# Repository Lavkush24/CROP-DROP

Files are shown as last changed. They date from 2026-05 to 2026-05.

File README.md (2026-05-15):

# 🌾 Crop Drop Bot — eYantra Robotics Competition 2025
### Team CB#3084 | Tasks 1 → 5

A fully autonomous line-following robot that detects coloured crop boxes,
navigates a grid arena via PID and Q-Learning, and physically picks up and
drops boxes at the correct destination zones.

---

## Table of Contents
- [Project Overview](#project-overview)
- [Robot Photos](#robot-photos)
- [Repository Structure](#repository-structure)
- [Task 1 — Environment Setup & Algorithm Design](#task-1)
- [Task 2 — Simulation: Color Detection, Navigation & Drop Logic](#task-2)
- [Task 3 — Hardware Assembly](#task-3)
- [Task 4 — Real Arena: Black Line Following](#task-4)
- [Task 5 — Dual Line Following (Black + White)](#task-5)
- [Key Technical Challenges & How I Solved Them](#challenges)
- [Hardware Stack](#hardware-stack)
- [Software Stack](#software-stack)
- [PID Tuning Reference](#pid-tuning)
- [How to Run](#how-to-run)
- [Demo Videos](#demo-videos)
- [Results](#results)

---

## Project Overview

The **Crop Drop Bot** is an autonomous robot designed for the eYantra 2025 competition.
It follows both black and white lines on a printed arena, reads the colour of cargo boxes
using an onboard colour sensor, communicates with a backend server, and deposits each
box at the matching colour-coded destination zone — all without human intervention.

The project progressed through five tasks, moving from pure simulation in CoppeliaSim
to a fully assembled physical robot running on a real printed arena. Tasks 1–4 were
completed successfully. The team was eliminated at Task 5 due to a hardware constraint:
no single IR sensor mounting height could produce readings that distinguished both
black and white lines reliably at the same time on the physical arena.

---

## Robot Photos

| Top view | Front view | Side view |
|:---:|:---:|:---:|
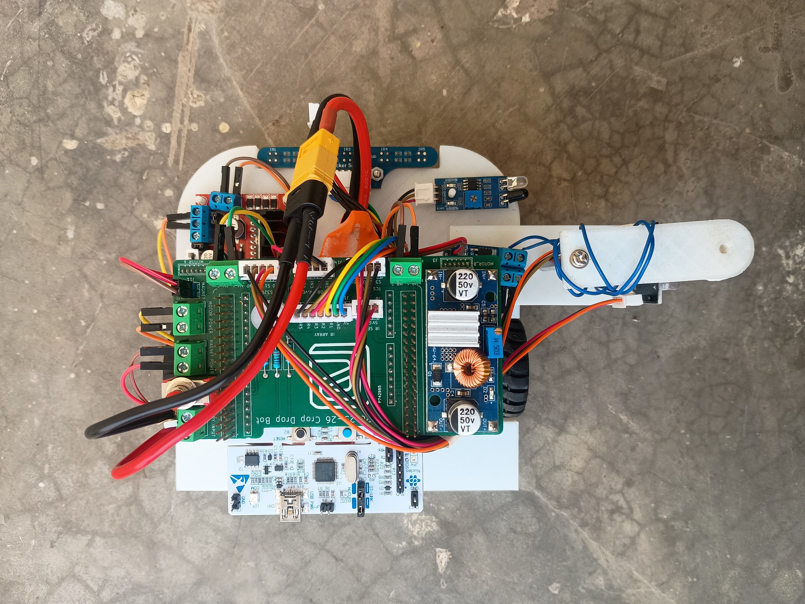
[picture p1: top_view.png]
Top view
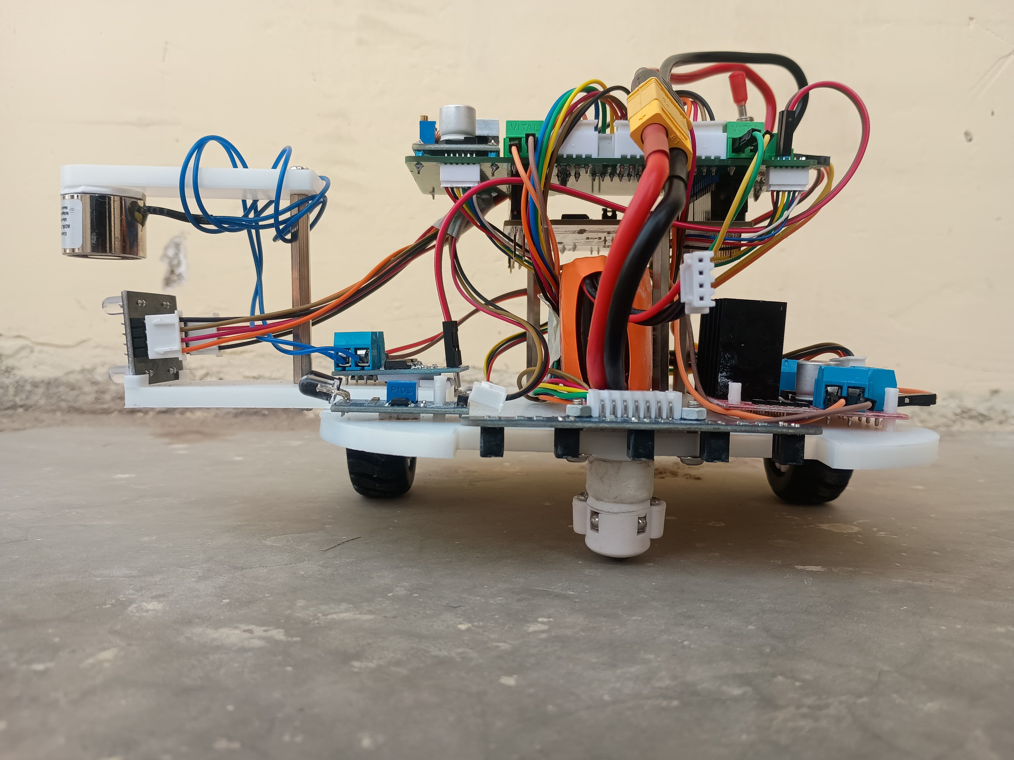
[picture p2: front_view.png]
Front view
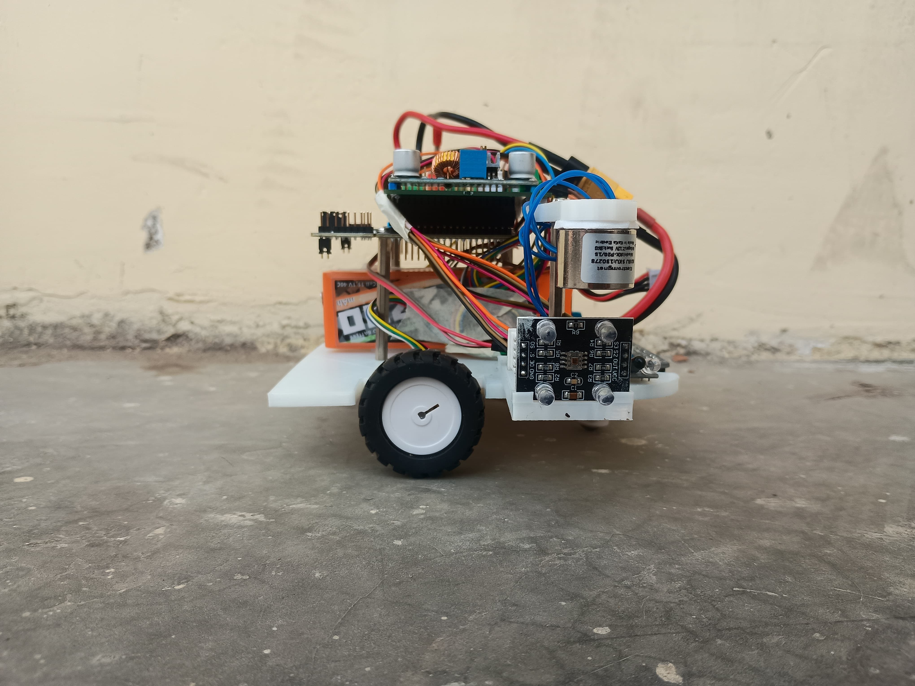
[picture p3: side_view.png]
Side view
|  |  |  |

---

## Repository Structure

```
crop_drop/
├── CB_3084_Task_1B_rl/          # Task 1B/1C — Q-Learning implementation
│   ├── Qlearning.py             #   Core Q-table training loop
│   ├── Train.py                 #   Training entry point
│   ├── Test.py                  #   Policy evaluation
│   ├── Connector.py             #   CoppeliaSim socket bridge
│   ├── wrapper/                 #   Environment wrapper
│   ├── q_table.pkl              #   Trained Q-table (binary)
│   └── result.json              #   Training metrics
│
├── crop_drop_task_2/            # Task 2 — Simulation navigation
│   ├── crop.txt                 #   Dev notes & sensor logs
│   ├── ubuntu 24-20251107T131635Z-1-001/   # PID implementation (Task 2A)
│   └── ubuntu 24-20251111T121329Z-1-001/   # RL algorithm using Q-Learning (Task 2B)
│
├── crop_drop_task_3/            # Task 3 — PCB & mechanical
│   ├── CB#3084_3A.zip           #   Onshape / 3D model files
│   ├── CB_PCB_schematics.pdf    #   PCB schematic
│   ├── CB_Gerber/               #   Gerber files for fabrication
│   ├── STEP files/              #   3D printable parts
│   ├── stm ioc files/           #   STM32 IOC config
│   └── Task3_arena_testing.ttt  #   CoppeliaSim scene
│
├── crop_drop_task_4/            # Task 4 — Black line, real arena
│   ├── Task4a_PID/              #   PID controller source
│   ├── Task4b_RL/               #   RL policy deployment
│   └── Verify_task4a/           #   Verification scripts
│
├── crop_drop_task_5/            # Task 5 — Dual line mode
│   └── Task5a_PID/              #   Combined black+white PID
│
├── top_view.png                 # Arena top-view reference photo
├── front_view.png               # Robot front view
├── side_view.png                # Robot side view
├── crop drop.txt                # CoppeliaSim sensor log (Task 2 development notes)
├── Crop Drop Testing.txt        # Real hardware build & PID tuning log (Task 3/4)
└── .gitignore
```

---

## Task 1 — Environment Setup & Algorithm Design 

### Task 1A — Ubuntu Setup
The competition required Ubuntu 24 as the working environment.

**What I did:**
- Installed Ubuntu 24 alongside Windows (dual-boot)
- Set up CoppeliaSim, Python 3, and all required simulation libraries
- Configured the socket communication bridge between Python and CoppeliaSim (`Connector.py`)

### Task 1B — PID Line Following
Implemented a classic 5-sensor weighted PID controller.

**Error calculation (weighted position):**
```
Sensor weights: [-2, -1, 0, 1, 2]
error = Σ(weight[i] × sensor[i]) / Σ(sensor[i])
```

**Tuned parameters (simulation):**
```
Kp = 1.45,  Ki = 0.03,  Kd = 0.01
base_speed = 4.0
```

### Task 1C — Reinforcement Learning (Q-Learning)
Implemented a tabular Q-Learning agent as an alternative to PID.

**Key design decisions:**
- State: discretised sensor reading pattern
- Actions: `[hard_left, left, straight, right, hard_right]`
- Reward: +10 on-line, −5 off-line, −1 per step
- Trained policy serialised to `q_table.pkl` and loaded at inference time

---

## Task 2 — Simulation: Color Detection, Navigation & Drop Logic 

This was the most algorithmically complex task, involving colour detection,
junction navigation, and precise drop placement — all inside CoppeliaSim.

### 2A — Color Detection

**Problem:** CoppeliaSim's rendering pipeline returns non-standard raw RGB values
that don't map intuitively to actual colours.

**Raw values observed (before normalisation):**

| Color | Raw R | Raw G | Raw B |
|---|---|---|---|
| Blue  | 0.098 | 0.000 | 0.000 |
| Red | 0.188 | 0.569 | 0.000 |
| Green | 0.188 | 0.000 | 0.569 |

**Fix — dominance mapping:** Rather than comparing absolute values,
I normalised the three channels and classified by whichever channel was dominant.
This made detection robust to the non-linear rendering pipeline.

### 2A — Junction Detection

The 5-sensor array gives distinct signatures at junctions vs. straight lines.

**Straight line:**
```
[0.83, 0.83, 0.03, 0.83, 0.83]   → outer 4 high, centre low
```

**Junction (T or cross):**
```
[0.83, 0.83, 0.03, 0.83, 0.83]   → multiple high readings fade
[0.83, 0.44, 0.03, 0.46, 0.83]   → then inner sensors drop
[0.62, 0.03, 0.03, 0.32, 0.63]   → transition zone
[0.37, 0.03, 0.03, 0.05, 0.03]   → robot centred on junction
```

**Condition to detect junction:**
```C
if(isBlack(c) && !junction && boxPicked) {
    printf("Node is detected\n");
    SLEEP(10);
    set_motor(c,0,0);
    
    printf("color of Box: %c\n",colorDetected);
    char dir = chooseDirection(colorDetected);
    printf("Turn Direction: %c \n",dir);
}
```

### 2A — Destination Zone Detection

Instead of using the colour sensor on the floor (unreliable at low angle),
I used the box color to detect the direction as its mapped for each color there sperate direction in which i need to move.

```C
char chooseDirection(char boxColor) {
    char dir;
    if(boxColor == 'R') {
        dir = 'L';
    }
    else if(boxColor == 'G') {
        dir = 'R';   
    }
    else if(boxColor == 'B') {
        dir = 'F';
    }
    return dir;   
}
```

### 2B — Dual Line Following + Full Path

**White line (inverted logic):**
White line = high reading on centre sensor, low on outer sensors.
```
[0.09, 0.09, 0.83, 0.09, 0.09]   ← centre sensor high = ON white line
```
Error computed by inverting weights so PID steers toward the high centre value.

**Black line (normal logic):**
Black line = low reading on the sensor directly above it, high on surroundings.
```
[0.83, 0.03, 0.83, 0.83, 0.83]   ← sensor 2 low = ON black line
```

**Line-type classifier:**
```cpp
bool isBlack(SocketClient* c) {
    float ir1 = c->line_sensors[0];  // left_corner sensor
    float ir2 = c->line_sensors[1];  // left sensor
    float ir3 = c->line_sensors[2];  // middle sensor (center)
    float ir4 = c->line_sensors[3];  // right sensor
    float ir5 = c->line_sensors[4];

    if(ir1 < 0.4 && ir2 < 0.4 && ir3 < 0.4 && ir4 < 0.4 && ir5 < 0.4) {
        return true;
    }
    return false;
}
```

**Corner conflict fix — `corner_duration` counter:**

At corners, the sensor array reads a mix of black+high values that momentarily
satisfy both black and white conditions. Adding a persistence counter (`corner_duration = 25`)
means the robot only switches line-type classification after 25 consecutive
matching frames, preventing thrashing.

```cpp
corner_duration = 25;  // frames the corner pattern must persist before acting
```

**PID re-tuning after box pickup:**

With the box loaded, the robot's centre of mass shifts and the effective turning
radius changes. Corners failed without a separate loaded-state PID set:

```
Unloaded:  Kp = 1.45, Ki = 0.03, Kd = 0.01
Loaded:    Kp = 1.10, Ki = 0.02, Kd = 0.05   (more damping, less aggression)
```

---

## Task 3 — Hardware Assembly 

### Mechanical
The chassis was split into three separate 3D-printed parts to make assembly and
sensor positioning adjustable:
- **Base** — motor mounts, wheel wells, main body
- **Colour sensor mount** — angled bracket to hold the sensor at correct reading height
- **Magnet holder** — gripper mechanism for picking up boxes

STEP files are in `crop_drop_task_3/STEP files/`.

### Electronics
- Microcontroller: STM32 Nucleo (configured via `.ioc` files)
- Motor drivers wired to the STM32 PWM outputs
- 5× IR reflectance sensors on underside bracket
- Colour sensor positioned to read boxes at pick-up height
- PCB designed in KiCad — Gerber files in `CB_Gerber/`

### Wiring reference
See `CB_PCB_schematics.pdf` for full schematic.

### How to read IR sensor output (hardware debug)
```bash
# Connect the Nucleo board via USB, then:
ls /dev/ttyACM*                              # find the port
putty -fn "Monospace 12"                     # launch PuTTY with readable font
# In PuTTY: Connection Type = Serial, Speed = 115200, Serial line = /dev/ttyACM0
```

### Bring-up: IR sensor ADC → reflectance conversion

Raw ADC values: maximum on white, minimum on black.
First step was converting to reflectance percentage (0 = black, 100 = white).

**Problem encountered:** the conversion was not producing middle values —
readings jumped directly between 0 and 100 with nothing in between.
This was traced to missing normalisation in the ADC-to-percentage mapping
and was fixed before PID tuning began.

### Real hardware PID tuning — the actual journey

The position error uses weighted sensors `{-2, -1, 0, 1, 2}` multiplied by 10
to give enough steering authority (raw weights alone were too small).

**Stage 1 — find critical Kp (Ki = Kd = 0):**

| Kp | Observed behaviour |
|---|---|
| 15 | Slight oscillation — borderline usable |
| 15–16 | ⭐ Critical point — oscillates but follows |
| 18 | Follows straight, won't turn at corners |
| 32 | Still won't turn |
| 46 | Very small turn — not usable |

Initial tuning stalled here because the position weights `{-2,-1,0,1,2}` were
too small. Multiplying by 10 gave enough correction range to actually steer.

**Stage 2 — add Kd to kill oscillation:**
```
Kd ≈ Kp × 0.2  →  Kd = 15 × 0.2 = 3
```

**Stage 3 — alignment issue:**
The bot followed straight paths but was physically offset — centred over sensor 4
instead of sensor 3. Two options considered:
- Individual sensor calibration *(correct long-term fix)*
- Setpoint offset `setPoint = -2.0f` *(used as temporary workaround)*

**Stage 4 — corner turning problem:**

At `base_speed = 80` the PID correction alone couldn't steer the robot through
corners. A `turn_boost` and `speed_scale` were added but caused jerky motion and
occasional line-loss.

The real fix was **dynamic speed** — reduce wheel speed proportionally to error
magnitude so the robot naturally slows at corners:

```c
dynamic_speed = base_speed - (k_speed * abs(error));
// At corners: error ≈ 1.5–2.0
// k_speed = 3  →  speed reduced by 4.5–6.0 at corners
```

**Stage 5 — dt term was missing from PID:**

The integral and derivative terms were not being scaled by `dt` (time between
updates). After adding it:
- At `Kp = 1, Ki = Kd = 0, base_speed = 120`: robot drifts
- At `Ki = 16`: robot starts turning — confirmed dt fix was working
- Behaviour from Ki = 16 to Ki = 50 was consistent (only zigzag amplitude changed)
  because at speed 120 the maximum PID correction was already at its steering limit

**Stage 6 — smooth speed ramp-up:**

Setting `turn_boost` and `speed_scale` as global variables caused the motors to
snap to the reduced corner speed on the very first corner and never recover.
A gradual speed ramp mechanism was needed — increase speed continuously rather
than jumping — similar to how a real vehicle accelerates.

**Final working parameters (Task 3 verification):**
```
Kp = 19,  Ki = 1,  Kd = 2
base_speed = 80,  min_speed = 10
speed_scale = 0.8,  turn_boost = 1.5,  k_speed = 3
Path accuracy: ~80%
```

---

## Task 4 — Real Arena: Black Line Following 

First full run on the **physically printed** competition arena, carrying forward
the hardware PID foundation from Task 3.

**Key differences encountered vs Task 3 bench testing:**
- Real arena ink has softer edges than the test track — junction thresholds loosened
- Reflective paper surface adds noise — moving-average smoothing added to sensor reads
- Motors don't respond linearly at low PWM — deadband compensation added

**PID re-tuned for full arena speed:**
```
Kp = 1.80,  Ki = 0.02,  Kd = 0.08
base_speed = 3.5  (reduced from 80 PWM units — arena safety margin)
```

Both PID (Task 4A) and RL policy from Task 1C (Task 4B) were deployed and compared.
PID outperformed RL on the physical arena because the Q-table was trained on
clean simulation sensor readings that don't match the noise profile of real hardware.

---

## Task 5 — Dual Line Following (Black + White) ⚠️ Elimination Point 

The Task 5 arena mixes both black and white line segments on the same track.
The robot must autonomously detect which type it is currently on and flip PID
error polarity accordingly.

**The software approach worked in simulation:**
```python
def detect_line_type(sensors):
    centre = sensors[2]
    outer_avg = (sensors[0] + sensors[4]) / 2
    if centre > 0.7 and outer_avg < 0.2:
        return "white"       # bright centre, dark edges
    elif centre < 0.2 and outer_avg > 0.7:
        return "black"       # dark centre, bright edges
    else:
        return "unknown"     # transition — hold last known type
```

### ❌ Why we were eliminated

**Root cause: IR sensor mounting height.**

In simulation both line types produced clean, separable readings because the
virtual sensors have no physical constraints. On the real robot, the 5 IR
sensors are fixed at one physical height above the floor.

The problem is that the threshold values that make white-line detection work
conflict with the threshold values needed for black-line detection at the same
mounting height:

| Sensor height | White line centre reading | Black line low reading | Conflict? |
|---|---|---|---|
| Too low | ~0.83 (saturated, clear) | ~0.03 (clear) | ✅ No conflict — but robot physically scrapes floor at turns |
| Optimal for black | ~0.55 (detectable) | ~0.03 (clear) | ⚠️ White-line readings drop into ambiguous range |
| Optimal for white | ~0.83 (clear) | ~0.35 (too high) | ⚠️ Black line no longer reads low enough to distinguish |

Every height we tried either made white-line detection unreliable or pushed the
black-line low reading up into the range where the classifier got confused during
transitions. The `corner_duration` filter that worked in Task 2 simulation was not
enough to mask the ambiguity on the physical track.

**What we tried:**
- Adjusting sensor array height in 1 mm increments (3 mm → 8 mm from floor)
- Recalibrating thresholds for each height separately
- Using a longer `corner_duration` window to filter transition noise
- Running at lower speed to give the sensor more time to settle

None of these resolved the fundamental overlap in reading ranges between the two
line types at a single fixed height.

**What would have fixed it:**
- An adjustable sensor arm that could tilt the array slightly (changes the
  effective angle, not just height) — small tilt changes white vs black contrast
  independently
- Using two separate sensor arrays at different heights, one tuned for each line
- A sensor with higher dynamic range so the two reading bands don't overlap

---

## Key Technical Challenges & How I Solved Them 

| Challenge | Root Cause | Solution |
|---|---|---|
| Wrong colour detection in sim | CoppeliaSim non-standard rendering pipeline | Channel-dominance normalisation instead of absolute RGB thresholds |
| IR sensor ADC not returning middle values | Missing normalisation in ADC-to-reflectance conversion | Fixed mapping so values span full 0–100 range |
| PID couldn't steer at corners (Kp up to 46) | Position weights `{-2,-1,0,1,2}` too small for enough correction range | Multiplied weights by 10 to give sufficient steering authority |
| Robot physically offset — followed line on sensor 4 not sensor 3 | Mechanical misalignment of sensor bracket | Temporary: `setPoint = -2.0f` offset. Proper fix: per-sensor calibration |
| Jerky motion at corners with `turn_boost` | Global speed variables snapped to corner values and never recovered | Replaced with `dynamic_speed = base_speed − (k_speed × |error|)` so speed reduces smoothly with error magnitude |
| Missing `dt` in PID made integral/derivative wrong | PID update loop ran at variable rate with no time scaling | Added `dt` term; re-tuned from scratch after fix |
| Junction over-detection | Transition frames look like junctions | Added consecutive-frame counter before triggering junction logic |
| Corner thrashing (black vs white) | Mixed sensor readings at corners | `corner_duration = 25` persistence filter |
| Robot can't turn after box pickup | Shifted CoM changes dynamics | Separate loaded/unloaded PID parameter sets |
| Floor colour undetectable by colour sensor | Sensor angle too shallow for flat surface | Switched to flat-value detection using line sensor array average |
| RL underperforms on real arena | Sim sensor noise doesn't match real hardware | Kept RL as fallback; deployed PID for competition runs |
| Black line junction readings change after pickup | Box blocks one sensor slightly | Re-calibrated junction threshold: all sensors `< 0.30` instead of `< 0.10` |
| ❌ **No single sensor height works for both line types** (Task 5 — **unsolved**) | Fixed sensor array height creates overlapping reading ranges for black and white lines on the physical robot | Tried height adjustments (3–8 mm), threshold recalibration, longer persistence window, lower speed — none fully resolved the overlap. Would need an angled/adjustable sensor arm or a dual-array setup |

---

## Hardware Stack 

| Component | Part |
|---|---|
| Microcontroller | STM32 |
| Motors | DC gear motors × 2 |
| Line sensors | IR reflectance array × 5 |
| Colour sensor | TCS3200 (or equivalent) |
| Gripper | Servo-actuated custom 3D-printed |
| Power | LiPo battery + regulator |
| Chassis | Custom 3D-printed (STEP files included) |

---

## Software Stack 

| Layer | Technology |
|---|---|
| Simulation | CoppeliaSim EDU |
| Robot–sim bridge | Python socket (`Connector.py`) |
| Control algorithm | PID + Q-Learning (Python) |
| Firmware | STM32 HAL (C) |
| Training | Custom Q-Learning (`Qlearning.py`) |
| Build system | Make / STM32CubeIDE |

---

## PID Tuning Reference 

```
Context                 Kp      Ki      Kd      base_speed
─────────────────────────────────────────────────────────
Sim — white line        1.45    0.03    0.01    4.0
Sim — black line        1.45    0.03    0.01    4.0
Sim — loaded (black)    1.10    0.02    0.05    3.5
Real arena (Task 4)     1.80    0.02    0.08    3.5
Real arena — loaded     1.30    0.02    0.10    3.0
```

---

## How to Run 

### Simulation (Tasks 1–2)

```bash
# 1. Open the scene in CoppeliaSim
#    File → Open → Task3_arena_testing_modified.ttt

# 2. Install Python dependencies
pip install -r requirements.txt

# 3. Train Q-Learning (Task 1C)
cd CB_3084_Task_1B_rl
python Train.py

# 4. Run PID controller
python Test.py --mode pid

# 5. Run RL controller
python Test.py --mode rl
```

### Real Hardware (Tasks 4–5)
float compute_line_conf(float *r)
{
    float s = 0.0f;
    for (int i = 0; i < NUM_SENSORS; i++) s += r[i];
    return s;
}
```bash
# Flash firmware via STM32CubeIDE
# Open project in crop_drop_task_4/Task4a_PID
# Build → Flash to board
# Place robot on arena start position → power on
```

---

## Demo Videos

> Click a thumbnail to open and play the video .

### Task 4 — Black line following on real arena

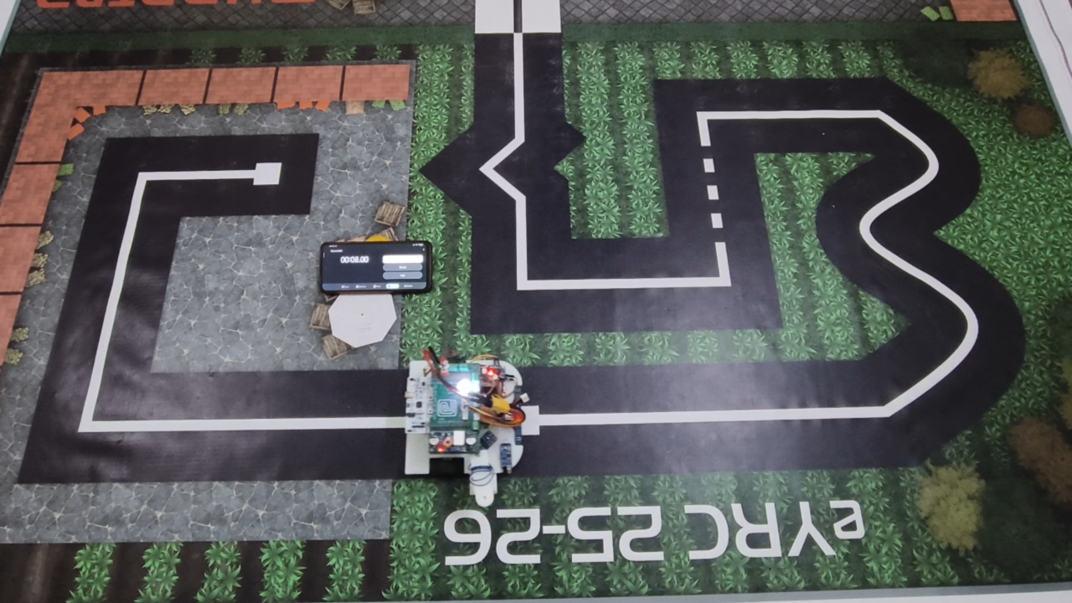
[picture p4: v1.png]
Task 4 run — black line (https://youtu.be/oO3rsXFNNNE)


### Task 4 —  Box pickup run

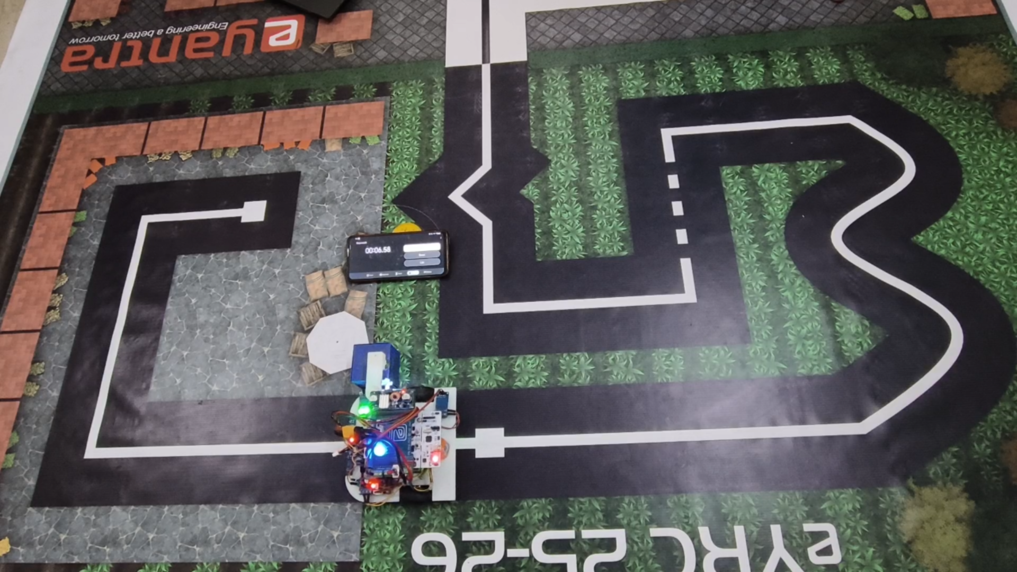
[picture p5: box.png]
Task 4 run — alternate angle (https://youtu.be/H0FVPsiAQus)


---

## Results

| Task | Status | Notes |
|---|---|---|
| 1A — Ubuntu setup | ✅ Complete | Dual-boot, CoppeliaSim configured |
| 1B — PID sim | ✅ Complete | Stable line following achieved |
| 1C — Q-Learning | ✅ Complete | Policy converges after ~500 episodes |
| 2A — Colour + nav | ✅ Complete | Junction stop + colour-directed routing |
| 2B — Dual line + pick/drop | ✅ Complete | Both line types, corner fix applied |
| 3 — Hardware assembly | ✅ Complete | Robot assembled and functional |
| 4 — Real arena black line | ✅ Complete | PID outperforms RL on real hardware |
| 5 — Dual line real arena | ❌ Eliminated | IR sensor reading ranges for black and white lines overlap at every tested mounting height; no single fixed position produced clean discrimination on the physical robot |

---

> **Competition:** eYantra Robotics Competition 2025
> **Team ID:** CB#3084
> **Theme:** Crop Drop Bot

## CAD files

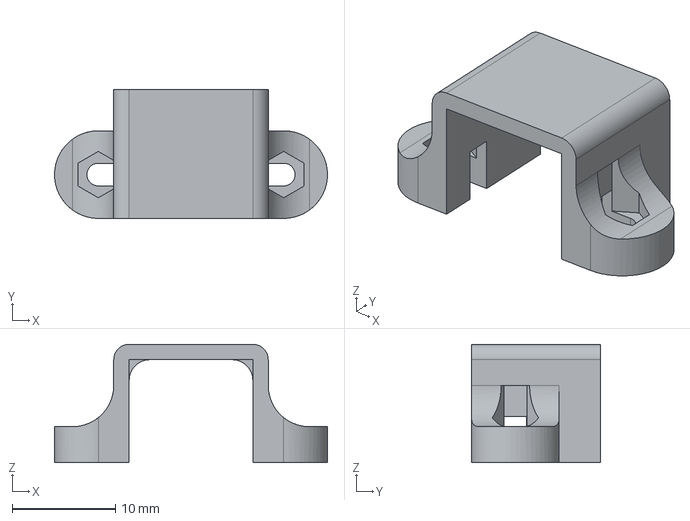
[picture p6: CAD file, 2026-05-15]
crop_drop_task_3/STEP files/motor mount-Body.step
26.5 x 12.5 x 11.5 mm

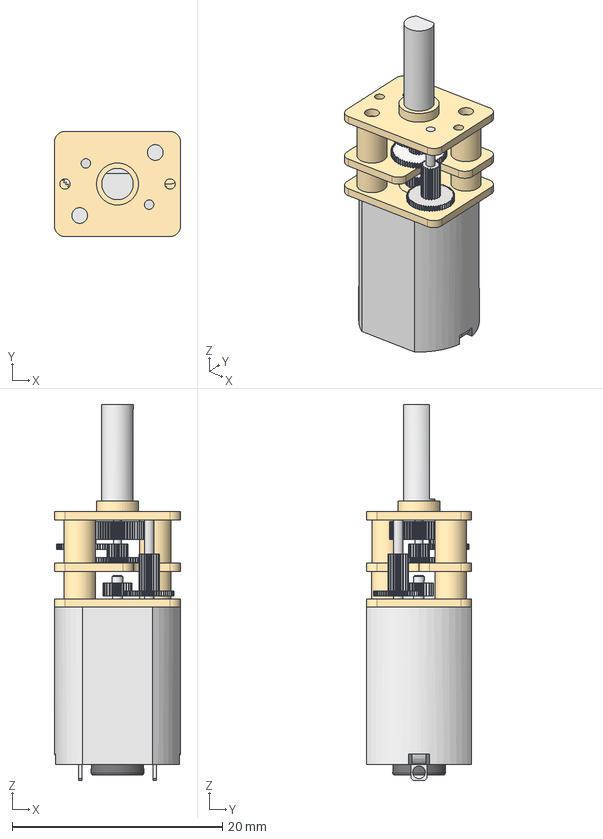
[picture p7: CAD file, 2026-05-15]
crop_drop_task_3/STEP files/n20-dc-gear-motor-1.snapshot.1/N20 DC Gear Motor/N20 DC Gear Motor.step
12.0 x 10.0 x 35.8 mm
Gear Box
Shaft
Motor

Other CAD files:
crop_drop_task_3/STEP files/n20-dc-gear-motor-1.snapshot.1/N20 DC Gear Motor/N20 DC Gear Motor.f3d

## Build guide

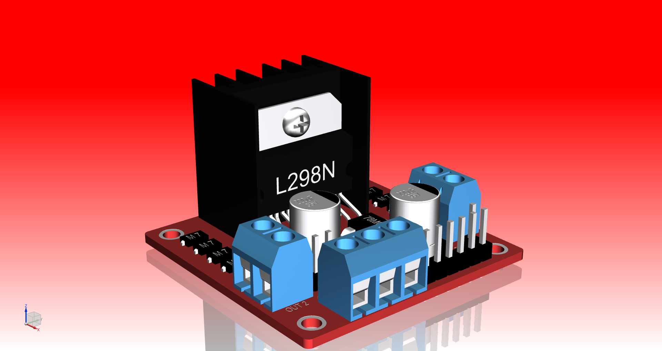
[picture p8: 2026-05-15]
crop_drop_task_3/STEP files/l295n-motor-driver-module-1.snapshot.2/L298NNN.png

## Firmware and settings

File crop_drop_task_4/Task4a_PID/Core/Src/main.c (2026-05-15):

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
/* Includes ------------------------------------------------------------------*/
#include "main.h"

/* USER CODE BEGIN Includes */
#include "stdio.h"
#include "stdlib.h"
#include "math.h"
#include "stdbool.h"
#include "stdint.h"

/* USER CODE END Includes */

/* USER CODE BEGIN PD */
#define NUM_SENSORS        5
#define BASE_SPEED         60
#define TURN_SPEED         BASE_SPEED * 2.2
#define GAP_SPEED          60
#define MAX_PWM            150
#define MIN_ACTIVE_PWM     10
#define LEFT_TRIM   	   0.92f
#define RIGHT_TRIM 		   1.00f

#define MAX_CORRECTION     30.0f
#define CORNER_TH          0.7f
#define TURN_TIME_MS       140

#define LINE_LOST_ENTER    0.45f
#define LINE_LOST_EXIT     0.65f
#define PIVOT_POS_TH       0.65f


// color detect
#define LED_R_PORT GPIOC
#define LED_R_PIN  GPIO_PIN_6

#define LED_G_PORT GPIOC
#define LED_G_PIN  GPIO_PIN_8

#define LED_B_PORT GPIOC
#define LED_B_PIN  GPIO_PIN_9

// obstacle detection
#define IR_OUT_PORT GPIOA
#define IR_OUT_PIN  GPIO_PIN_15

// magnet
#define EM_PORT GPIOA
#define EM_PIN  GPIO_PIN_4

/* USER CODE END PD */

ADC_HandleTypeDef hadc1;
DMA_HandleTypeDef hdma_adc1;

TIM_HandleTypeDef htim2;
TIM_HandleTypeDef htim3;

UART_HandleTypeDef huart2;

/* USER CODE BEGIN PV */

/* helper function required */

typedef struct {
	float kp;
	float ki;
	float kd;
	float prev_error;
	float integral;
} PID_t;

typedef enum {
    MODE_TRACK,
    MODE_PIVOT,
    MODE_GAP,
	PICK_BOX,
	NODE_MODE
} ControlMode;

//static int slow_hold = 0;
volatile uint16_t adcBuffer[5];
char buffer[64];

float black[5];
float white[5];


// color detection
volatile uint32_t capture1 = 0, capture2 = 0;
volatile uint8_t  captureDone = 0;
volatile uint32_t frequency = 0;

typedef enum {
    COLOR_UNKNOWN,
    COLOR_RED,
    COLOR_GREEN,
    COLOR_BLUE
} DetectedColor;

static uint32_t led_last_tick = 0;
static uint8_t  led_on = 0;
static DetectedColor led_color = COLOR_UNKNOWN;

//static float prev_pos = 0.0f;
float speed_scale = 1.0f;
static float last_pos = 0.0f;
static bool in_gap = false;
static bool box_picked = false;

/* USER CODE END PV */

void SystemClock_Config(void);
static void MX_GPIO_Init(void);
static void MX_DMA_Init(void);
static void MX_USART2_UART_Init(void);
static void MX_ADC1_Init(void);
static void MX_TIM2_Init(void);
static void MX_TIM3_Init(void);


/* USER CODE BEGIN PFP */

// hardware control functions
void custom_control(int left,int right);

// helper functions
int clamp(int val,int min,int max);
float clampFloat(float v, float min, float max);
void pidInit(PID_t *pid,float kp,float ki,float kd);
void ir_state(const uint16_t *adc, uint8_t *state);
void readIR(uint16_t *dst);
void computeReflectance(uint16_t* adcBuffer, float *ir_reflectance);
float position_reflectance(const float *ir);
float position_states(uint8_t *state);
float pid_compute(PID_t *pid, float error, float dt);
void set_threshold(uint16_t* adcBuffer);
void calibrate_sensor(uint32_t duration_ms);



float compute_line_conf(float *r);
void control_track(float steer, float speed,float left_scale, float right_scale,int *left, int *right);
void control_pivot(float pos, int *left, int *right);
void control_gap(float last_pos, int *left, int *right);

// colord erection
DetectedColor TCS3200_DetectColor(void);
void LED_BlinkColor(DetectedColor color, uint32_t period_ms);
uint32_t Read_Color_Frequency(uint8_t s2, uint8_t s3);
uint8_t IR_ObjectDetected(void);

/* USER CODE END PFP */

/* USER CODE BEGIN 0 */
static inline void Electromagnet_ON(void)
{
    HAL_GPIO_WritePin(EM_PORT, EM_PIN, GPIO_PIN_SET);
}

static inline void Electromagnet_OFF(void)
{
    HAL_GPIO_WritePin(EM_PORT, EM_PIN, GPIO_PIN_RESET);
}

static inline void LED_AllOff(void)
{
    HAL_GPIO_WritePin(LED_R_PORT, LED_R_PIN, GPIO_PIN_SET);
    HAL_GPIO_WritePin(LED_G_PORT, LED_G_PIN, GPIO_PIN_SET);
    HAL_GPIO_WritePin(LED_B_PORT, LED_B_PIN, GPIO_PIN_SET);
}

static inline void LED_SetColor(DetectedColor color)
{
    LED_AllOff();  // important

    switch (color)
    {
    case COLOR_RED:
        HAL_GPIO_WritePin(LED_R_PORT, LED_R_PIN, GPIO_PIN_RESET);
        break;

    case COLOR_GREEN:
        HAL_GPIO_WritePin(LED_G_PORT, LED_G_PIN, GPIO_PIN_RESET);
        break;

    case COLOR_BLUE:
        HAL_GPIO_WritePin(LED_B_PORT, LED_B_PIN, GPIO_PIN_RESET);
        break;

    default:
        // unknown → all off
        break;
    }
}



/* USER CODE END 0 */

/**
  * @brief  The application entry point.
  * @retval int
  */
int main(void)
{

  /* MCU Configuration--------------------------------------------------------*/

  /* Reset of all peripherals, Initializes the Flash interface and the Systick. */
  HAL_Init();

  /* Configure the system clock */
  SystemClock_Config();

  /* Initialize all configured peripherals */
  MX_GPIO_Init();
  MX_DMA_Init();
  MX_USART2_UART_Init();
  MX_ADC1_Init();
  MX_TIM2_Init();
  MX_TIM3_Init();

  /* USER CODE BEGIN 2 */
  HAL_ADC_Start_DMA(&hadc1,(uint32_t*)adcBuffer,5);
  HAL_Delay(200);

  calibrate_sensor(5000);

  // motor control pin configuration
  HAL_TIM_PWM_Start(&htim2, TIM_CHANNEL_1);
  HAL_TIM_PWM_Start(&htim2, TIM_CHANNEL_2);
  HAL_TIM_PWM_Start(&htim2, TIM_CHANNEL_3);
  HAL_TIM_PWM_Start(&htim2, TIM_CHANNEL_4);


  // color freq
  HAL_GPIO_WritePin(GPIOB, GPIO_PIN_12, GPIO_PIN_SET);
  HAL_GPIO_WritePin(GPIOB, GPIO_PIN_13, GPIO_PIN_SET);
  HAL_TIM_IC_Start_IT(&htim3, TIM_CHANNEL_1);

  PID_t linePID;
  pidInit(&linePID, 15.0f, 0.0f, 0.0f);

  uint32_t lastTick = HAL_GetTick();

  /* USER CODE END 2 */

  /* Infinite loop */
  /* USER CODE BEGIN WHILE */
  while (1)
  {
	  // -------------------- Time --------------------
	  uint32_t now = HAL_GetTick();
	  float dt = (now - lastTick) / 1000.0f;
	  lastTick = now;

	  if (dt <= 0.0f || dt > 0.1f)
	      dt = 0.01f;

	  // -------------------- Sensors --------------------
	  uint16_t ir[NUM_SENSORS];
	  float reflectance[NUM_SENSORS];
	  readIR(ir);
	  computeReflectance(ir, reflectance);
	  // -------------------- Position --------------------
	  float pos = position_reflectance(reflectance);   // pos < 0 : left, pos > 0 : right

	  // color detection
	  DetectedColor color = TCS3200_DetectColor();
	  bool box = IR_ObjectDetected();

	  if(color != COLOR_UNKNOWN && !box_picked) {
		  LED_SetColor(color);
	  }
	  else {
		  LED_SetColor(COLOR_UNKNOWN);
	  }

	  bool stop_condition = reflectance[0] == 1.0 && reflectance[4] == 1.0 && reflectance[3] != 1.0;

	  float line_conf = compute_line_conf(reflectance);

	  if (line_conf > LINE_LOST_EXIT)
		  last_pos = pos;

	  if (!in_gap && line_conf < LINE_LOST_ENTER)
		  in_gap = true;
	  else if (in_gap && line_conf > LINE_LOST_EXIT)
		  in_gap = false;


	  // ---------- PID ----------
	  float error = -pos;
	  float steer = pid_compute(&linePID, error, dt);
	  steer = clampFloat(steer, -MAX_CORRECTION, MAX_CORRECTION);

	  // ---------- Corner detection ----------
	  static bool iscorner = false;
	  static uint32_t corner_time = 0;
	  static uint8_t corner_cnt = 0;

	  bool left_edge  = reflectance[0] > CORNER_TH;
	  bool right_edge = reflectance[4] > CORNER_TH;


	  if (!iscorner) {
		  if (left_edge || right_edge) {
			  corner_cnt++;
			  if (corner_cnt >= 2) {
				  iscorner = true;
				  corner_time = HAL_GetTick();
			  }
		  } else {
			  corner_cnt = 0;
		  }
	  }

	  if (iscorner && (HAL_GetTick() - corner_time > TURN_TIME_MS)) {
		  iscorner = false;
		  corner_cnt = 0;
	  }

	  ControlMode mode ;
	  if(stop_condition) {
		  mode = NODE_MODE;
	  }
	  else if(box && color != COLOR_UNKNOWN && !box_picked) {
		  mode = PICK_BOX;
	  }
	  else
	  if (iscorner && fabs(pos) > PIVOT_POS_TH) {
		  mode = MODE_PIVOT;
	  }
	  else if (in_gap && !iscorner && fabs(pos) < 0.4f) {
		  mode = MODE_GAP;
	  }
	  else {
		  mode = MODE_TRACK;
	  }

//	   debug
//	  int len = 0;
//	  for(int i=0; i<5; i++) {
//		  len += snprintf(buffer+len,sizeof(buffer)-len,"ir%d: %.2f",i+1,reflectance[i]);
//	  }
//
//	  buffer[len++] = '\r';
//	  buffer[len++] = '\n';
//
//	  HAL_UART_Transmit(&huart2,(uint8_t*) buffer, len, HAL_MAX_DELAY);
//	  HAL_Delay(500);

	  // ---------- Speed & scaling ----------
	  float speed = BASE_SPEED;
	  float left_scale = 1.0f;
	  float right_scale = 1.0f;

	  if (iscorner && mode == MODE_TRACK) {
		  steer = clampFloat(steer, -5.0f, 5.0f);
		  speed = TURN_SPEED;

		  if (pos < 0) {
			  left_scale  = 0.1f;
			  right_scale = 1.5f;
		  } else {
			  left_scale  = 1.5f;
			  right_scale = 0.1f;
		  }

		  if (steer < 0)
			  steer *= 1.3f;   // right-turn boost only
	  }


	  // ---------- Actuation ----------
	  int left = 0, right = 0;

	  switch (mode) {
	  case PICK_BOX:
		  custom_control(40,40);
		  box_picked = true;
		  HAL_Delay(300);
		  Electromagnet_ON();
		  break;
	  case NODE_MODE:
		  custom_control(-100,100);
//		  LED_BlinkColor(color, 300);
//		  Electromagnet_OFF();
		  HAL_Delay(1100);
//		  box_picked = false;
		  break;
	  case MODE_PIVOT:
		  control_pivot(pos, &left, &right);
		  break;

	  case MODE_GAP:
		  control_gap(last_pos, &left, &right);
		  break;

	  case MODE_TRACK:
	  default:
		  control_track(steer, speed, left_scale, right_scale, &left, &right);
		  break;
	  }


	  left = (int)(left*LEFT_TRIM);
	  right = (int)(right*RIGHT_TRIM);
	  custom_control(left, right);


	  // motor check
//	  custom_control(0,100);


//	  // color detection
//
//	  DetectedColor color = TCS3200_DetectColor();
//	  LED_SetColor(color);
//
//
//	  // object detection
//	  uint8_t box = IR_ObjectDetected();
//
//	  // magner pickup
//	  if(box) {
//		  Electromagnet_ON();
//	  }
//	  else {
//		  Electromagnet_OFF();
//	  }

  }
  /* USER CODE END 3 */
}

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
/* USER CODE BEGIN 4 */

//void custom_control(int left, int right) {
//	__HAL_TIM_SET_COMPARE(&htim2,TIM_CHANNEL_1,right);
//	__HAL_TIM_SET_COMPARE(&htim2,TIM_CHANNEL_2,0);
//	__HAL_TIM_SET_COMPARE(&htim2,TIM_CHANNEL_3,0);
//	__HAL_TIM_SET_COMPARE(&htim2,TIM_CHANNEL_4,left);
//}



void custom_control(int left, int right)
{
    // clamp
    if (left > MAX_PWM)  left = MAX_PWM;
    if (left < -MAX_PWM) left = -MAX_PWM;
    if (right > MAX_PWM)  right = MAX_PWM;
    if (right < -MAX_PWM) right = -MAX_PWM;

    // -------- LEFT MOTOR --------
    if (left >= 0) {
        __HAL_TIM_SET_COMPARE(&htim2, TIM_CHANNEL_1, left);   // forward
        __HAL_TIM_SET_COMPARE(&htim2, TIM_CHANNEL_2, 0);      // reverse off
    } else {
        __HAL_TIM_SET_COMPARE(&htim2, TIM_CHANNEL_1, 0);      // forward off
        __HAL_TIM_SET_COMPARE(&htim2, TIM_CHANNEL_2, -left);  // reverse
    }

    // -------- RIGHT MOTOR --------
    if (right >= 0) {
        __HAL_TIM_SET_COMPARE(&htim2, TIM_CHANNEL_3, right);  // forward
        __HAL_TIM_SET_COMPARE(&htim2, TIM_CHANNEL_4, 0);      // reverse off
    } else {
        __HAL_TIM_SET_COMPARE(&htim2, TIM_CHANNEL_3, 0);      // forward off
        __HAL_TIM_SET_COMPARE(&htim2, TIM_CHANNEL_4, -right); // reverse
    }
}




// helper function implementation

//void set_threshold(uint16_t* adcBuffer) {
//	for(int i=0; i<5; i++) {
//		if(adcBuffer[i] < )
//	}
//}
void pidInit(PID_t *pid,float kp,float ki,float kd) {
	pid->kp = kp;
	pid->kd = kd;
	pid->ki = ki;
	pid->integral = 0.0f;
	pid->prev_error = 0.0f;
}

int clamp(int v, int min, int max)
{
    if (v < min) return min;
    if (v > max) return max;
    return v;
}

float clampFloat(float v, float min, float max)
{
    if (v < min) return min;
    if (v > max) return max;
    return v;
}

void readIR(uint16_t *dst)
{
    for (int i = 0; i < NUM_SENSORS; i++)
        dst[i] = adcBuffer[i];
}


//void ir_state(const uint16_t *adc, uint8_t *state)
//{
//    for (int i = 0; i < NUM_SENSORS; i++) {
//        if (adc[i] > WHITE_TH + MARGIN)
//            state[i] = 2; // WHITE
//        else if (adc[i] < BLACK_TH - MARGIN)
//            state[i] = 0; // BLACK
//        else
//            state[i] = 1; // EDGE
//    }
//}

void calibrate_sensor(uint32_t duration_ms)
{
    for (int i = 0; i < 5; i++) {
        black[i] = 4095.0f;
        white[i] = 0.0f;
    }

    uint32_t start = HAL_GetTick();

    while (HAL_GetTick() - start < duration_ms)
    {
        for (int i = 0; i < 5; i++)
        {
            uint16_t v = adcBuffer[i];

            if (v < black[i]) black[i] = v;
            if (v > white[i]) white[i] = v;
        }

        HAL_Delay(2);
    }

    // Safety margin to avoid divide_zero and noise
    for (int i = 0; i < 5; i++) {
        if (white[i] - black[i] < 200) {
            white[i] = black[i] + 200;
        }
    }
}


//void adaptiveCalibration(const uint16_t *adc)
//{
//    for (int i = 0; i < NUM_SENSORS; i++)
//    {
//        if (adc[i] > white[i]) {
//            white[i] = white[i] * (1.0f - CAL_ALPHA)
//                     + adc[i]   * CAL_ALPHA;
//        }
//
//        if (adc[i] < black[i]) {
//            black[i] = black[i] * (1.0f - CAL_ALPHA)
//                     + adc[i]   * CAL_ALPHA;
//        }
//
//        if (white[i] - black[i] < MIN_RANGE) {
//            white[i] = black[i] + MIN_RANGE;
//        }
//    }
//}

void computeReflectance(uint16_t* adcBuffer, float *ir_reflectance)
{
    for (int i = 0; i < 5; i++)
    {
        float denom = white[i] - black[i];
        if (denom < 1.0f)
            denom = 1.0f;

        float r = ((float)adcBuffer[i] - black[i]) / denom;

        if (r < 0.0f) r = 0.0f;
        if (r > 1.0f) r = 1.0f;

        ir_reflectance[i] = r;
    }
}


float position_reflectance(const float *ir)
{
    static float last_pos = 0.0f;
    const float w[5] = { -2, -1, 0, 1, 2 };

    float sum = 0.0f;
    float weighted = 0.0f;

    for (int i = 0; i < 5; i++) {
        float r = clampFloat(ir[i], 0.0f, 1.0f);
        sum += r;
        weighted += r * w[i];
    }

    if (sum < 0.5f) {
        return last_pos;   // HOLD
    }

    float pos = weighted / (sum + 0.3f);  // soft floor
    pos = clampFloat(pos, -2.0f, 2.0f);

    last_pos = pos;
    return pos;
}

float position_states(uint8_t *state)
{
	const int weight[5] = { -2, -1, 0, 1, 2 };
	float sum = 0.0f;
	float count = 0.0f;

	for (int i = 0; i < NUM_SENSORS; i++) {
		if (state[i] == 2) {
			sum += weight[i];
			count++;
		}
	}

	if (count == 0)
		return 0.0f;

	return sum / count;
}

bool cornerDetection(int *ir) {
	if((ir[0] == 0 && ir[1] == 0) || (ir[3] == 0 && ir[4] == 0)) {
		if((ir[3] == 100 && ir[4] == 100) || (ir[0] == 100 && ir[1] == 100)) {
			return true;
		}
	}
	return false;
}


float pid_compute(PID_t *pid, float error, float dt)
{
    pid->integral += error * dt;
    pid->integral = clampFloat(pid->integral, -10.0f, 10.0f);

    float derivative = (error - pid->prev_error) / dt;
    pid->prev_error = error;

    return pid->kp * error +
           pid->ki * pid->integral +
           pid->kd * derivative;
}



float compute_line_conf(float *r)
{
    float s = 0.0f;
    for (int i = 0; i < NUM_SENSORS; i++) s += r[i];
    return s;
}

void control_track(float steer, float speed,float left_scale, float right_scale,int *left, int *right)
{
    if (steer > 0) {
        *left  = speed * left_scale;
        *right = speed * right_scale + steer;
    } else {
        *left  = speed * left_scale - steer;
        *right = 0;
    }

    *left  = clamp(*left,  MIN_ACTIVE_PWM, MAX_PWM);
    *right = clamp(*right, MIN_ACTIVE_PWM, MAX_PWM);
}


void control_pivot(float pos, int *left, int *right)
{
    if (pos > 0) {
        *left  = TURN_SPEED;
        *right = 0;
    } else {
        *left  = 0;
        *right = TURN_SPEED;
    }
}


void control_gap(float last_pos, int *left, int *right)
{
    if (last_pos > 0) {
        *left  = GAP_SPEED;
        *right = GAP_SPEED * 0.6f;
    } else {
        *left  = GAP_SPEED * 0.6f;
        *right = GAP_SPEED;
    }
}

// color detection]


DetectedColor TCS3200_DetectColor(void)
{
    uint32_t red, green, blue;
    float r, g, b, sum;

    red   = Read_Color_Frequency(GPIO_PIN_RESET, GPIO_PIN_RESET); // RED
    green = Read_Color_Frequency(GPIO_PIN_SET,   GPIO_PIN_SET);   // GREEN
    blue  = Read_Color_Frequency(GPIO_PIN_RESET, GPIO_PIN_SET);   // BLUE

    if (red == 0 || green == 0 || blue == 0)
        return COLOR_UNKNOWN;

    sum = red + green + blue;
    r = red   / sum;
    g = green / sum;
    b = blue  / sum;

    if (r > 0.45f && r > g && r > b)
        return COLOR_RED;

    // BLUE: strong, absolute threshold OK
    if (b > 0.40f && b > r && b > g)
        return COLOR_BLUE;

    // GREEN: weak channel → relative dominance only
    if (g > r * 1.08f && g > b * 1.08f)
        return COLOR_GREEN;

    return COLOR_UNKNOWN;
}



void LED_BlinkColor(DetectedColor color, uint32_t period_ms)
{
    uint32_t now = HAL_GetTick();

    // Color changed → reset blink state
    if (color != led_color) {
        led_color = color;
        led_on = 0;
        LED_AllOff();
        led_last_tick = now;
    }

    if (color == COLOR_UNKNOWN)
        return;

    if (now - led_last_tick >= period_ms) {
        led_last_tick = now;
        led_on ^= 1;

        if (led_on)
            LED_SetColor(color);
        else
            LED_AllOff();
    }
}

uint32_t Read_Color_Frequency(uint8_t s2, uint8_t s3)
{
    HAL_GPIO_WritePin(GPIOB, GPIO_PIN_14, s2);
    HAL_GPIO_WritePin(GPIOB, GPIO_PIN_15, s3);

    captureDone = 0;
    while (captureDone < 2);

    return frequency;
}

uint8_t IR_ObjectDetected(void)
{
    // ACTIVE LOW sensor
    if (HAL_GPIO_ReadPin(IR_OUT_PORT, IR_OUT_PIN) == GPIO_PIN_RESET)
        return 1;   // object detected
    else
        return 0;   // no object
}

/* USER CODE END 4 */
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


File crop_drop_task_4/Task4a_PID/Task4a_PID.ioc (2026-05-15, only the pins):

Mcu.UserName=STM32F103RBTx
PA0-WKUP.GPIO_Label=IN1
PA0-WKUP.Signal=S_TIM2_CH1_ETR
PA1.GPIO_Label=IN2
PA1.Signal=S_TIM2_CH2
PA13.GPIO_Label=TMS
PA13.Signal=SYS_JTMS-SWDIO
PA14.GPIO_Label=TCK
PA14.Signal=SYS_JTCK-SWCLK
PA15.GPIO_Label=Box_detect
PA15.Signal=GPIO_Input
PA2.GPIO_Label=USART_TX
PA2.Signal=USART2_TX
PA3.GPIO_Label=USART_RX
PA3.Signal=USART2_RX
PA4.GPIO_Label=Electromagnet
PA4.Signal=GPIO_Output
PA5.GPIO_Label=LD2 [Green Led]
PA5.Signal=GPIO_Output
PA6.GPIO_Label=Color_out
PA6.Signal=S_TIM3_CH1
PB0.GPIO_Label=IR4
PB0.Signal=ADCx_IN8
PB1.GPIO_Label=IR5
PB1.Signal=ADCx_IN9
PB10.GPIO_Label=In3
PB10.Signal=S_TIM2_CH3
PB11.GPIO_Label=IN4
PB11.Signal=S_TIM2_CH4
PB12.GPIO_Label=S0
PB12.Signal=GPIO_Output
PB13.GPIO_Label=S1
PB13.Signal=GPIO_Output
PB14.GPIO_Label=S2
PB14.Signal=GPIO_Output
PB15.GPIO_Label=S3
PB15.Signal=GPIO_Output
PB3.GPIO_Label=SWO
PB3.Signal=SYS_JTDO-TRACESWO
PC0.GPIO_Label=IR1
PC0.Signal=ADCx_IN10
PC1.GPIO_Label=IR2
PC1.Signal=ADCx_IN11
PC13-TAMPER-RTC.GPIO_Label=B1 [Blue PushButton]
PC13-TAMPER-RTC.Signal=GPXTI13
PC14-OSC32_IN.Signal=RCC_OSC32_IN
PC15-OSC32_OUT.Signal=RCC_OSC32_OUT
PC2.GPIO_Label=IR3
PC2.Signal=ADCx_IN12
PC6.GPIO_Label=RED
PC6.Signal=GPIO_Output
PC8.GPIO_Label=GREEN
PC8.Signal=GPIO_Output
PC9.GPIO_Label=BLUE
PC9.Signal=GPIO_Output
PD0-OSC_IN.Signal=RCC_OSC_IN
PD1-OSC_OUT.Signal=RCC_OSC_OUT

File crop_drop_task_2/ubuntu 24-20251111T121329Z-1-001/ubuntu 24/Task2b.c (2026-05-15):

// Platform-specific includes for Windows compatibility
#ifdef _WIN32
    #define WINVER 0x0600
    #define _WIN32_WINNT 0x0600
    #include <winsock2.h>
    #include <ws2tcpip.h>
#endif

#include "coppeliasim_client.h"  // Include our header
#include <sys/time.h>
#include <math.h>
#include <string.h>

// Global client instance for socket communication
SocketClient client;
void* control_loop(void* arg);

/**
 * @brief Establishes connection to the CoppeliaSim server
 */
int connect_to_server(SocketClient* c, const char* ip, int port) {
#ifdef _WIN32
    // Initialize Winsock on Windows
    WSADATA wsa;
    if (WSAStartup(MAKEWORD(2, 2), &wsa) != 0) {
        printf("WSAStartup failed\n");
        return 0;
    }
#endif
    
    // Create TCP socket
    c->sock = socket(AF_INET, SOCK_STREAM, 0);
    if (c->sock < 0) {
        printf("Socket creation failed\n");
        return 0;
    }

    // Setup server address structure
    struct sockaddr_in serv_addr;
    memset(&serv_addr, 0, sizeof(serv_addr));
    serv_addr.sin_family = AF_INET;
    serv_addr.sin_port = htons(port);
    inet_pton(AF_INET, ip, &serv_addr.sin_addr);

    // Attempt to connect to server
    if (connect(c->sock, (struct sockaddr*)&serv_addr, sizeof(serv_addr)) < 0) {
        printf("Connection failed\n");
        CLOSESOCKET(c->sock);
#ifdef _WIN32
        WSACleanup();
#endif
        return 0;
    }

    c->running = true;

    // Start the receive thread to handle incoming sensor data
#ifdef _WIN32
    c->recv_thread = CreateThread(NULL, 0, (LPTHREAD_START_ROUTINE)receive_loop, c, 0, NULL);
#else
    pthread_create(&c->recv_thread, NULL, receive_loop, c);
#endif

    return 1;
}

/**
 * @brief Get current time in seconds
 */
double get_current_time() {
    struct timeval tv;
    gettimeofday(&tv, NULL);
    return tv.tv_sec + tv.tv_usec / 1000000.0;
}

/*
from task 2a for pick and drop one box and follow black line
*/
// float Kp = 1.2, Ki = 0.04, Kd = 0.012;   // parameter for black line 

float Kp = 1.45, Ki = 0.01, Kd = 0.012; // parameter for white line
float baseSpeed_white = 3.0f;

float Kp_b = 1.5 , Ki_b = 0.03, Kd_b = 0.01;  //parameter for black line
float baseSpeed_black = 4.0f;

float Kp_corner = 3.8 , Ki_corner = 0.0, Kd_corner = 0.01;
float baseSpeed_corner = 2.0f;

float Kp_concave = 10.0;
float Kd_concave = 0.0;
float baseSpeed_concave = 1.8f;


int CORNER_HOLD_TIME = 35;
int CORNER_HOLD_TIME_CONCAVE = 20;


bool junction = false;
bool black = false;
float setPoint = 0.0;

float integral = 0, prevError = 0;
float dt = 0.01;
unsigned long prevTime = 0;

bool boxPicked = false; // exp
int color_counter = 0; // exp
char color[3] = {'N','N','N'};
bool destination = false;
int corner_hold = 0;
int concave_hold = 0;


bool detectConcaveTurn(SocketClient* c) {
    float ir1 = c->line_sensors[0];
    float ir2 = c->line_sensors[1];
    float ir3 = c->line_sensors[2];
    float ir4 = c->line_sensors[3];
    float ir5 = c->line_sensors[4];

    // EARLY concave entry detection
    bool concaveRight = (ir3 > 0.70  &&  ir5 > 0.30  &&  ir4 > 0.10);
    bool concaveLeft = (ir3 > 0.70 && ir1 > 0.30 && ir2 > 0.10);

    return concaveRight || concaveLeft;
}


bool detectSharpCorner(SocketClient *c) {
    // Detects sharp 90-degree corners
    float ir1 = c->line_sensors[0];
    float ir2 = c->line_sensors[1];
    float ir3 = c->line_sensors[2];
    float ir4 = c->line_sensors[3];
    float ir5 = c->line_sensors[4];
    
    // Left sharp corner: both left sensors see line
    bool leftCorner = (ir1 > 0.3 && ir2 > 0.3 && ir3 < 0.25);
    
    // Right sharp corner: both right sensors see line
    bool rightCorner = (ir4 > 0.3 && ir5 > 0.3 && ir3 < 0.25);
    
    return leftCorner || rightCorner;
}


bool isJunction(SocketClient* c) {
    int count = 0;
    for(int i=0; i<5; i++) {
        if(c->line_sensors[i] > 0.02 && c->line_sensors[i] < 0.3){
            count++;
        }
    }
    return count == 5 ? true : false;
}

bool blackLine(SocketClient *c) {
    int first = c->line_sensors[2];
    int sec = 0;

    for(int i=0; i<5; i++) {
        if(c->line_sensors[i] > 0.7) {
            sec++;
        }
    }
    return (first < 0.08 && sec > 3) ? true : false;
}

float position(float sensor[],int s,bool black_line) {
    float weight[] = {-2, -1, 0, +1, +2};
    float sumSen = 0;
    float sumSenWeg = 0;

    if(black_line) {
        Kp = Kp_b, Ki = Ki_b, Kd = Kd_b; 
    }

    for(int i =0; i<s; i++) {
        float sensorValue = 0.0;
        if(black_line) {
            sensorValue = 1.0f - sensor[i];  // for the inversion of line detection from white to black
        }else if(!black_line){
            sensorValue = sensor[i];
        }
        sumSen += sensorValue;
        sumSenWeg += (sensorValue*weight[i]);
    }

    if(sumSen == 0) return 0.0f;
    return sumSenWeg/sumSen ;
}


float normalize(float x,float oldMin,float oldMax,float newMin,float newMax) {
    return ((x - oldMin) / (oldMax - oldMin)) * (newMax - newMin) + newMin;
}

char detectColor(float r,float g,float b) {
    char color = 'N';
    if(r > 0.0 || g > 0.0 || b > 0.0) {
        if(g > 0.5 && r > 0.1 && b < 0.02) {
            color = 'R';
        }
        else if(g < 0.01 && r >= 0.1 && b > 0.3) {
            color = 'G';
        }
        else if(r > 0.1 && g < 0.08 && b < 0.08) {
            color = 'B';
        }
    }
    return color;
}


int thersholdreading(SocketClient *c) {
    int counter = 0;
    for(int i =0; i<5; i++) {
        if((c->line_sensors[i] > 0.45 && c->line_sensors[i] < 0.55) || (c->line_sensors[i] > 0.25 && c->line_sensors[i] < 0.35)) {
            counter++;
        }
    }
    return counter;
}


char chooseDirection(char boxColor) {
    char dir;
    if(boxColor == 'R' || boxColor == 'G') {
        dir = 'L';
    }
    else if(boxColor == 'B'){
        dir = 'R';   
    }
    return dir;   
}


bool validColor(char color[],char c) {
    for(int i=0; i<3; i++) {
        if(color[i] == c) {
            return false;
        }
    }
    return true;
}
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

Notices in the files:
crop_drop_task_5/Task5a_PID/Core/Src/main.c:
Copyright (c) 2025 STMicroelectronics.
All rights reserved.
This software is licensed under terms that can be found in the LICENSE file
